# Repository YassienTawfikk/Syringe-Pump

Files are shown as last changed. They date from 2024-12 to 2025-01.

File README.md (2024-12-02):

# Syringe-Pump

The project integrates several advanced components such as a stepper motor, flow sensor, and a DS18B20 temperature sensor, with an LCD providing real-time data display. Its modular design allows for precise fluid control, temperature monitoring, and real-time alerts, making it versatile and adaptable for various applications like infusion pumps, chemical dispensing, and more.

### **1. Project Overview**
- **Brief Description:** The Syringe Pump project is a precise, programmable fluid dispensing system designed to meet a variety of medical and laboratory needs. This system leverages a stepper motor-driven syringe mechanism, real-time monitoring, and user-friendly feedback interfaces to achieve controlled fluid flow.

#### **Key Features**
- **Precision Control**:
  - Accurate syringe movement powered by a stepper motor with 1.8° step angle (200 steps/revolution).
  - Adjustable flow rates monitored and displayed on the LCD.
  
- **Real-Time Monitoring**:
  - Integrated flow sensor tracks fluid dispensing in mL/min.
  - DS18B20 sensor monitors system or environmental temperature.

- **User Feedback**:
  - LED indicator for alarms or warnings (e.g., high temperature).
  - Real-time data display on a 16x2 I2C LCD.

- **Emergency Control**:
  - Emergency stop buttons provide safety and control during operation.

- **Versatility**:
  - Easily adaptable for various syringe sizes and fluid viscosities.
  
This project serves as an excellent foundation for building intelligent medical or laboratory devices requiring precise fluid control and real-time monitoring capabilities.

---

### **2. Components List**

| **Component** | **Quantity** | **Specification** or **Model** |
|---|---|---|
| Arduino Board | 1 | Any compatible model (e.g., Arduino Uno)  |
| Stepper Motor | 1 | Mercury Motor SM 42BYG011-25 |
| Stepper Motor Driver | 1 | Any compatible driver |
| Flow Sensor | 1 | YF-S201 |
| Temperature Sensor | 1 | DS18B20 |
| I2C LCD Display | 1 | 16x2 (0x27 address) |
| Resistors | 2 | 220Ω for LED, 4.7kΩ for DS18B20 |
| LED | 1 | Standard LED |
| Power Supply | 1 | 12V battery + Arduino-powered 5V |
| Syringe | 1 | For fluid dispensing |
| Miscellaneous | - | Jumper wires, breadboard, etc. |

---
### **3. Connections**

### **Stepper Motor**
- **Model:** Mercury Motor SM 42BYG011-25
- **Specifications:**
  - Step Angle: **1.8°** (200 steps per revolution)
  - Rated Voltage: **12V**
  - Current: **0.33A**
  - Holding Torque: **2.5 kg.cm**
- **Integration:** The stepper motor is connected to a stepper motor driver, which interfaces with the Arduino.

### **Stepper Motor Driver**
- **Description:** The stepper motor driver controls the motion of the stepper motor based on signals received from the Arduino.
- **Connections:**
  - **STEP_PIN (D3):** Connected to the STEP pin of the stepper motor driver (controls the stepping pulse).
  - **DIR_PIN (D2):** Connected to the DIR pin of the stepper motor driver (controls rotation direction).
  - **ENABLE_PIN (D4):** Connected to the EN pin of the stepper motor driver (enables/disables the motor).
  - **Power Connections:**
    - **VCC1 & GND1:** Connected to the Arduino 5V and ground, respectively.
    - **VCC2 & GND2:** Connected to a **12V battery** and its ground to power the motor.
  - **Motor Output:** The driver outputs are connected to the stepper motor’s coils to generate motion.

### **Flow Sensor**
- **Description:** The flow sensor is used to monitor the flow rate of the fluid passing through the syringe hub.
- **Connections:**
  - **Signal (D6):** Connected to the **FLOW_SENSOR_PIN**.
  - **Power (VCC):** Connect to **5V**.
  - **Ground (GND):** Connect to Arduino ground.
- **Usage:** Provides real-time flow rate data in mL/min, linked to the syringe hub for fluid monitoring.

### **Syringe Hub**
- **Integration:** The syringe hub is driven by the stepper motor, with the flow sensor monitoring the output. This setup enables precise control and real-time feedback of fluid dispensing.

### **LED**
- **Purpose:** Visual indicator for system warnings (e.g., high temperature).
- **Connection:**
  - **LED_PIN (D5):** Connected to the LED anode.
  - **Resistor (220Ω):** In series with the LED to limit current.
  - **Cathode:** Connected to Arduino ground.

### **Temperature Sensor (DS18B20)**
- **Model:** Dallas DS18B20 Digital Temperature Sensor
- **Connections:**
  - **Data (D7):** Connected to **ONE_WIRE_BUS**.
  - **Power (VCC):** Connect to **5V**.
  - **Ground (GND):** Connect to Arduino ground.
  - **Pull-Up Resistor:** **4.7kΩ** resistor between data and VCC.

### **LCD Display**
- **Model:** I2C 16x2 LCD
- **Connections:**
  - **SDA:** Connect to Arduino **SDA** (A4 on UNO or dedicated SDA pin).
  - **SCL:** Connect to Arduino **SCL** (A5 on UNO or dedicated SCL pin).
  - **Power (VCC):** Connect to **5V**.
  - **Ground (GND):** Connect to Arduino ground.

---

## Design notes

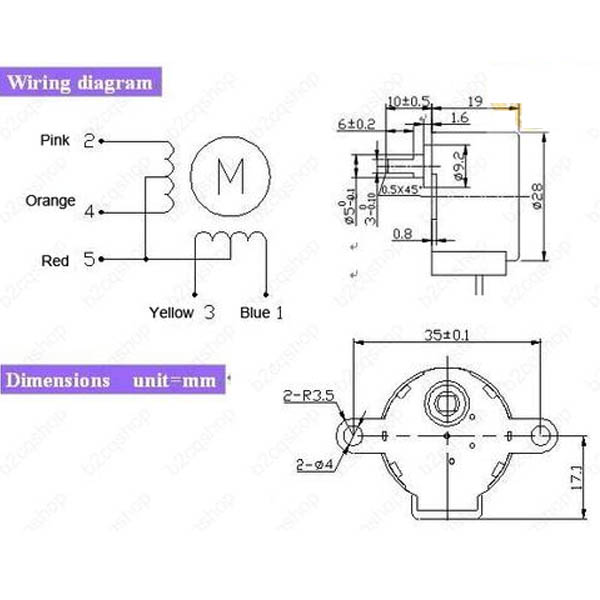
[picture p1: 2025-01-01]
Hardware/Stepper_Motor_Diagram.jpg

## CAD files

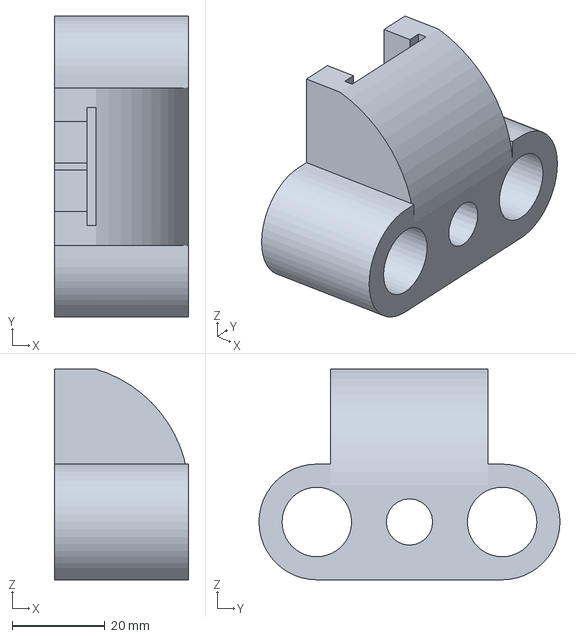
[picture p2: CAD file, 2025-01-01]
Hardware/3D_Models/3D_Carriage_Model.3mf
29.0 x 65.0 x 45.5 mm

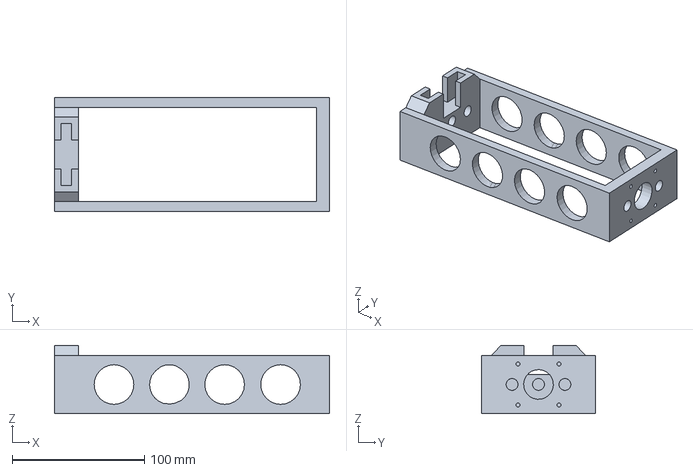
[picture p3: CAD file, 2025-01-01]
Hardware/3D_Models/3D_Chassis_Model.3mf
208.0 x 86.0 x 51.5 mm

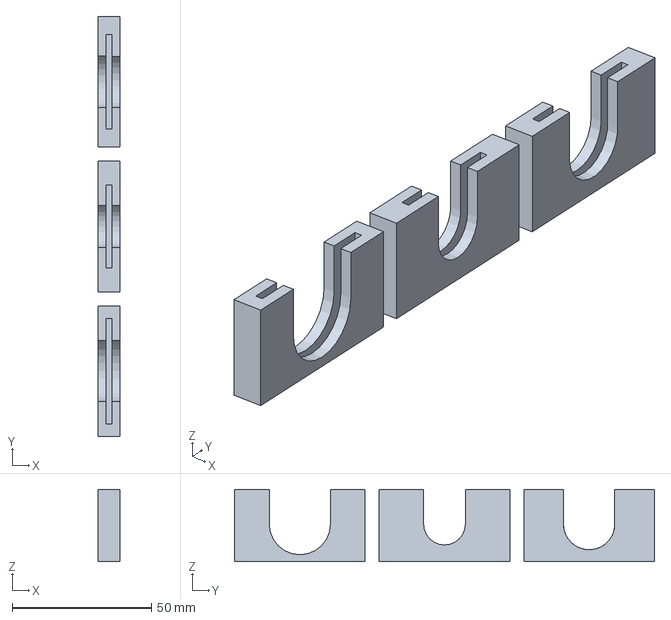
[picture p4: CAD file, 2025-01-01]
Hardware/3D_Models/3D_Holders_Model.3mf
8.00 x 151.0 x 26.0 mm

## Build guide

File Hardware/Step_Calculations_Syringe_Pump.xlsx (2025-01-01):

Part Description | Type | Step angle (deg) | Microstep | Pitch (mm)
Stepper Motor | BJ42D15-26V09 | 1.8
Stepper Driver | TMC2208 |  | 16
Leadscrew | M5x0.8 |  |  | 0.8
 |  |  |  | Steps/mm | 4000
 |  |  |  | Min. Movement (mm) | 0.00025
Fill in the inner diameter (ID) of syringe
Syringe | ID (mm) | Area (mm^2) | V/mm (mL) | V/step (mL) | Steps/mL (n)
1 mL | 4.7 | 17.34944543 | 0.01734944543 | 4.337361357e-06 | 230554.9198
5 mL | 12.3 | 118.8228881 | 0.1188228881 | 2.970572204e-05 | 33663.54801
10 mL | 15.6 | 191.134497 | 0.191134497 | 4.778362426e-05 | 20927.67168
20 mL | 20.1 | 317.308712 | 0.317308712 | 7.9327178e-05 | 12606.0201

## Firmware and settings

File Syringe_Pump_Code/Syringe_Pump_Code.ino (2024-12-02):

#include <Wire.h>
#include <LiquidCrystal_I2C.h>  // Library for I2C LCD
#include <OneWire.h>
#include <DallasTemperature.h> // Library for DS18B20 temperature sensor

#define STEP_PIN 3       // Step pin connected to driver STEP
#define DIR_PIN 2        // Direction pin connected to driver DIR
#define ENABLE_PIN 4     // Enable pin connected to driver EN
#define LED_PIN 5        // LED connected to D5
#define FLOW_SENSOR_PIN 6 // Flow sensor signal connected to D6
#define ONE_WIRE_BUS 7   // DS18B20 data pin connected to pin 7 on Arduino

const int stepsPerRevolution = 200; // Steps for one full rotation (1.8° step motor)
int rotations = 50;                 // Global variable: number of rotations
volatile int flowPulseCount = 0;    // Counter for the number of pulses from the flow sensor
float flowRate = 0.0;               // Flow rate in mL/min
unsigned long lastFlowTime = 0;     // Timestamp for flow rate calculation
bool isMotorRunning = false;        // Tracks whether the motor is running

// Calibration factor (pulses per liter)
const float calibrationFactor = 7.5 * 22;

// Initialize the LCD (Address: 0x27, 16 columns and 2 rows)
LiquidCrystal_I2C lcd(0x27, 16, 2);

// Temperature Sensor Setup
OneWire oneWire(ONE_WIRE_BUS);
DallasTemperature sensors(&oneWire);

void setup() {
  // Set up pins
  pinMode(STEP_PIN, OUTPUT);
  pinMode(DIR_PIN, OUTPUT);
  pinMode(ENABLE_PIN, OUTPUT);
  pinMode(LED_PIN, OUTPUT);
  pinMode(FLOW_SENSOR_PIN, INPUT_PULLUP); // Set the flow sensor pin as input with pull-up

  // Initialize motor and LED states
  digitalWrite(ENABLE_PIN, LOW);  // Enable motor driver
  digitalWrite(LED_PIN, LOW);     // Turn off LED

  // Initialize LCD
  lcd.init();        // Initialize the LCD
  lcd.backlight();   // Turn on the backlight
  lcd.setCursor(0, 0);
  lcd.print("Initializing...");
  delay(2000);       // Display message for 2 seconds

  lcd.clear();
  lcd.setCursor(0, 0);
  lcd.print("Ready to Start");

  // Initialize Serial Monitor
  Serial.begin(9600);

  // Initialize Temperature Sensor
  sensors.begin();
}

void loop() {
  // Calculate flow rate
  calculateFlowRate();

  // Update LCD display when motor is idle
  if (!isMotorRunning) {
    float temperature = getTemperature();
    updateLCD(temperature);
  }

  // Start motor operation
  performRotations(rotations);
}

void performRotations(int numRotations) {
  int steps = numRotations * stepsPerRevolution;  // Total steps for the given rotations

  digitalWrite(DIR_PIN, LOW); // Set direction (anti-clockwise)
  Serial.print("Performing ");
  Serial.print(numRotations);
  Serial.println(" rotations.");

  isMotorRunning = true; // Motor is now running

  for (int i = 0; i < steps; i++) {
    float temperature = getTemperature();

    // Check for high temperature and pause motor if necessary
    if (temperature > 38) {
      pauseMotor();
      isMotorRunning = false;
      return; // Exit motor operation
    }

    digitalWrite(STEP_PIN, HIGH);
    delayMicroseconds(2000);  // Adjust speed
    digitalWrite(STEP_PIN, LOW);
    delayMicroseconds(2000);
  }

  isMotorRunning = false; // Motor is no longer running
}

void pauseMotor() {
  // Disable the motor and alert user
  digitalWrite(ENABLE_PIN, HIGH);  // Disable motor driver
  digitalWrite(LED_PIN, HIGH);     // Turn on warning LED

  // Display a warning message on the LCD
  lcd.clear();
  lcd.setCursor(0, 0);
  lcd.print("Motor Paused");
  lcd.setCursor(0, 1);
  lcd.print("High Temp!");

  Serial.println("Motor paused due to high temperature.");
  delay(5000); // Wait for 5 seconds before rechecking
}

void calculateFlowRate() {
  // Calculate flow rate every second
  unsigned long currentTime = millis();

  if (currentTime - lastFlowTime >= 1000) {
    // Calculate flow rate in mL/min
    flowRate = (flowPulseCount / calibrationFactor);
    lastFlowTime = currentTime;

    // Reset the pulse count for the next calculation
    flowPulseCount = 0;

    // Debugging: Print flow rate to Serial Monitor
    Serial.print("Flow Rate: ");
    Serial.print(flowRate);
    Serial.println(" mL/min");
  }
}

float getTemperature() {
  sensors.requestTemperatures();  // Request temperature from the sensor
  float temp = sensors.getTempCByIndex(0);

  // Handle disconnected sensor
  if (temp == DEVICE_DISCONNECTED_C) {
    Serial.println("Error: Sensor not connected!");
    return -999;  // Return an invalid value to indicate error
  }

  Serial.print("Temperature: ");
  Serial.println(temp);
  return temp;
}

void updateLCD(float temperature) {
  lcd.clear(); // Clear the screen to prevent overlap

  // First line: Display temperature
  lcd.setCursor(0, 0);
  if (temperature == -999) {
    lcd.print("Temp Error!");
  } else {
    lcd.print("Temp: ");
    lcd.print(temperature, 1); // Display temperature with 1 decimal place
    lcd.print(" C");
  }

  // Second line: Real-time flow rate
  lcd.setCursor(0, 1);
  lcd.print("Rate: ");
  lcd.print(flowRate, 1); // Display flow rate with 1 decimal point
  lcd.print(" mL/min");
}
